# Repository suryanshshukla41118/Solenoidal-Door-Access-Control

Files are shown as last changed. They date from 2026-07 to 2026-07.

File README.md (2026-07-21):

# 🔐 Solenoid Door Access Control

An Arduino Nano–based electronic door lock system that replaces traditional mechanical keys with PIN-based authentication. Enter the correct password on a 4×4 keypad and a relay-driven solenoid lock retracts to grant access — wrong entries are rejected, logged, and locked out after repeated failures.

Designed end-to-end: schematic → PCB layout → fabrication-ready Gerbers → firmware.

---

## ✨ Features

- 🔢 **4×4 keypad PIN entry** with masked input on a 16×2 LCD
- 🔒 **Fail-safe default-locked state** — solenoid stays locked unless explicitly triggered
- ⏱️ **Auto re-lock** after a configurable unlock window
- 🚫 **Brute-force protection** — lockout timer after repeated failed attempts
- 🔁 **In-field password change** (old PIN → new PIN) with **EEPROM storage** so it survives power loss
- 🔊 **Audible + visual feedback** via buzzer and green/red status LEDs
- 🖥️ Custom two-layer **PCB** designed and routed from scratch (Gerbers + drill files included)

---

## ⚙️ How It Works

1. On power-up, the Arduino initializes all peripherals and keeps the solenoid **locked** by default.
2. The user enters a 4-digit PIN on the keypad; each digit is masked on the LCD.
3. Pressing `#` submits the PIN for verification against the stored value.
4. **Correct PIN** → relay energizes the solenoid, door unlocks, green LED + short beep, auto re-locks after a timeout.
5. **Incorrect PIN** → red LED + buzzer alert, door stays locked; after 3 failed attempts the system enters a 15-second lockout.
6. Pressing `A` at any time opens a guided password-change flow, storing the new PIN in EEPROM.

**Governing physics** (solenoid actuation):

```
F ∝ N · I          (Force generated by current through coil)
B = μNI / L         (Magnetic field in the coil)
V = IR              (Ohm's Law — current through solenoid)
P = V · I           (Power consumption, for supply/relay sizing)
```

---

## 🧰 Hardware

| Component | Details |
|---|---|
| **Microcontroller** | Arduino Nano (ATmega328P) |
| **Input** | 4×4 matrix keypad (PIN entry) |
| **Display** | 16×2 LCD (parallel interface) |
| **Actuator** | 12V DC solenoid door lock |
| **Driver** | Relay module (+ flyback diode for back-EMF protection) |
| **Feedback** | Buzzer, green LED (access granted), red LED (access denied) |
| **Power** | 5V for logic, 9–12V external supply for the solenoid |

### Pin Map (Arduino Nano)

| Function | Pin(s) |
|---|---|
| LCD (RS, E, D4–D7) | 12, 11, 5, 4, 3, 2 |
| Keypad Rows | A0, A1, A2, A3 |
| Keypad Columns | 6, 7, 8, 9 |
| Relay (solenoid driver) | 10 |
| Buzzer | A4 |
| Green LED | A5 |
| Red LED | 13 |

> Adjust pin assignments in the firmware if your wiring/PCB differs.

---

## 🖥️ Software

- **Firmware**: Arduino IDE (C/C++), using `Keypad.h`, `LiquidCrystal.h`, and `EEPROM.h`
- **Schematic capture & PCB layout**: Altium Designer
- **Circuit simulation**: Proteus VSM
- **Fabrication outputs**: Gerber (RS-274X) + Excellon drill files

---

## 🔩 PCB Design

A custom two-layer PCB was designed to host the Nano, relay, buzzer, OLED, keypad header, and power input — laid out and routed manually in Altium Designer, then exported to industry-standard Gerber/drill files for fabrication.

**Component placement (silkscreen legend):**

Keypad header, Buzzer, Relay, Nano footprint, OLED display, and 9–12V power input footprint, arranged for clean routing and minimal trace crossover.

**Signal routing (top + bottom copper):**

Signal traces connect the keypad rows/columns, relay control line, OLED I²C/SPI lines, and power rails between the Nano and peripheral footprints, with dedicated power pours for the 9–12V solenoid supply.

**Drill report summary:**

| Tool | Hole Size | Count | Type |
|---|---|---|---|
| T1 | 0.8 mm | 2 | PTH |
| T2 | 0.9 mm | 41 | PTH |
| T3 | 1.0 mm | 4 | PTH |
| T4 | 2.0 mm | 4 | PTH |
| T5 | 3.35 mm | 2 | PTH |
| T6 | 3.74 mm | 1 | PTH |

**54 total plated through-holes**, all routed with a top-to-bottom layer pair.

> Gerber files (`PCB1_Profile`, `PCB1_Legend_Top`, `PCB1_Copper_Signal_Top/Bot`) and the drill report (`PCB1.DRR`) are included in [`/hardware`](./hardware) for anyone who wants to fabricate the board.

---

## 📁 Repository Structure

```
├── firmware/
│   └── Solenoid_Door_Access_Control.ino   # Main Arduino sketch
├── hardware/
│   ├── PCB1_Profile.gbr
│   ├── PCB1_Legend_Top.gbr
│   ├── PCB1_Copper_Signal_Top.gbr
│   ├── PCB1_Copper_Signal_Bot.gbr
│   ├── PCB1.apr
│   └── PCB1.DRR
└── README.md
```

---

## 🚀 Getting Started

### 1. Hardware Assembly
Wire the components per the [pin map](#pin-map-arduino-nano) above, or fabricate the included PCB and populate it with the listed components.

### 2. Flash the Firmware
1. Open `firmware/Solenoid_Door_Access_Control.ino` in the Arduino IDE.
2. Install the required libraries via Library Manager: `Keypad`, `LiquidCrystal` (built-in), `EEPROM` (built-in).
3. Select **Board: Arduino Nano** and the correct COM port.
4. Upload.

### 3. Default Credentials
- Default PIN: `1234`
- Change it any time by pressing `A` on the keypad and following the on-screen prompts.

---

## 🛡️ Design Considerations

- **Fail-safe locking**: the solenoid defaults to locked on boot and on power loss — the door never fails open.
- **Back-EMF protection**: a flyback diode across the relay coil protects the driver transistor when the solenoid de-energizes.
- **Brute-force resistance**: a 3-strike lockout with a cooldown period discourages rapid PIN guessing.

## 🔮 Future Improvements

- RFID / NFC card authentication as a secondary input method
- Wi-Fi/Bluetooth module for remote unlock and access logging
- OTP-based one-time access codes
- Real-time access logging to an SD card or cloud endpoint

---

## 📜 License

This project is open-source — feel free to use, modify, and build on it. Consider adding a license file (e.g., MIT) if you plan to share it publicly.

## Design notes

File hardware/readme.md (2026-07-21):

# 🔐 Solenoid Door Access Control

An Arduino Nano–based PIN authentication door lock. Enter your PIN on a 4×4 keypad — correct entries release a relay-driven solenoid, wrong entries get rejected and locked out after repeated tries.

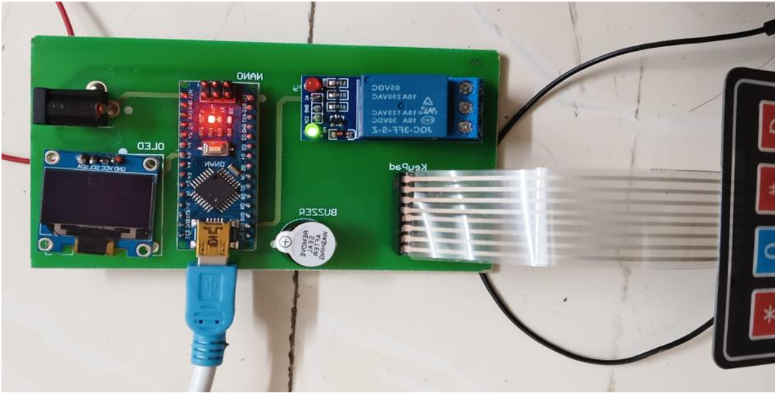
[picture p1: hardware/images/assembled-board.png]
Assembled Board


## Quick Overview
- 4×4 keypad PIN entry with LCD feedback
- Fail-safe: stays locked by default
- Auto re-lock + brute-force lockout after failed attempts
- In-field PIN change, saved to EEPROM
- Custom 2-layer PCB (Gerbers included)

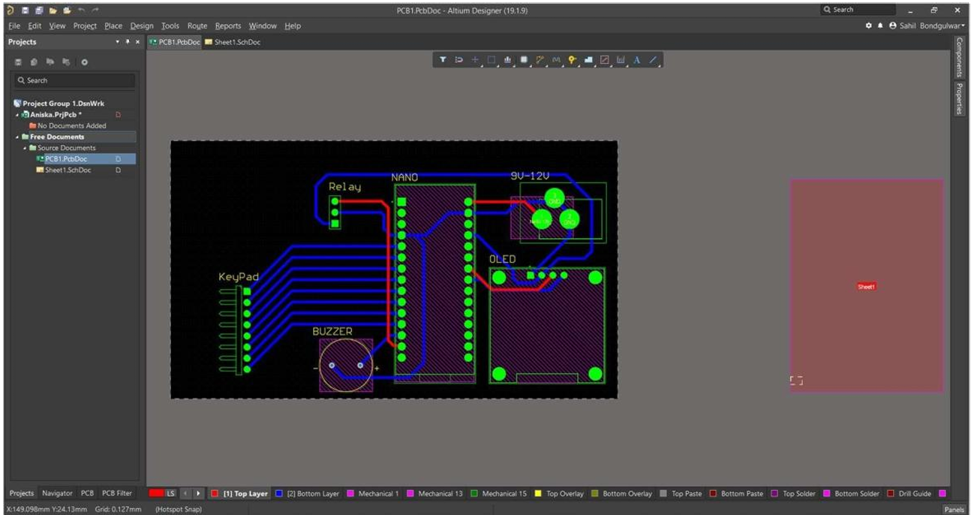
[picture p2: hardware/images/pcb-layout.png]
PCB Layout


## Hardware
Arduino Nano · 4×4 keypad · 16×2 LCD · 12V solenoid · relay module · buzzer + LEDs

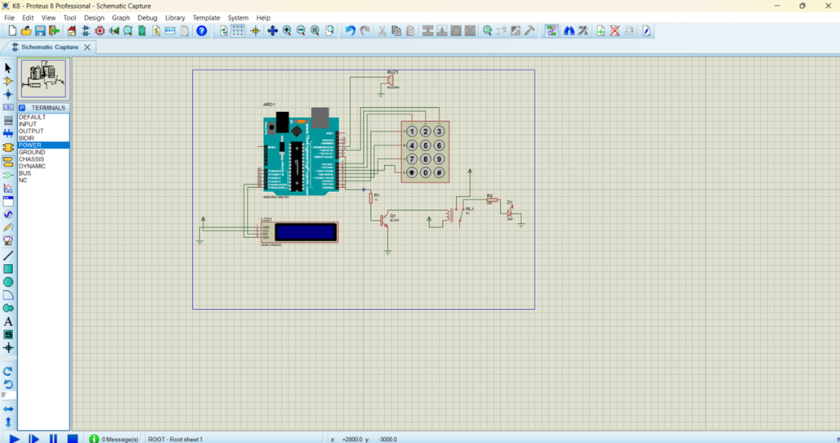
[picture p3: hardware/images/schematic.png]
Schematic


## Getting Started
1. Wire per the pin map (see full README) or use the included PCB
2. Flash `firmware/Solenoid_Door_Access_Control.ino` via Arduino IDE
3. Install libraries: `Keypad`, `LiquidCrystal`, `EEPROM`
4. Default PIN is `1234` — change it anytime with the `A` key

## Full Details
See the main [README](./README.md) for pin mapping, PCB drill report, repo structure, and design notes.

## License
Open-source — feel free to use, modify, and build on it.

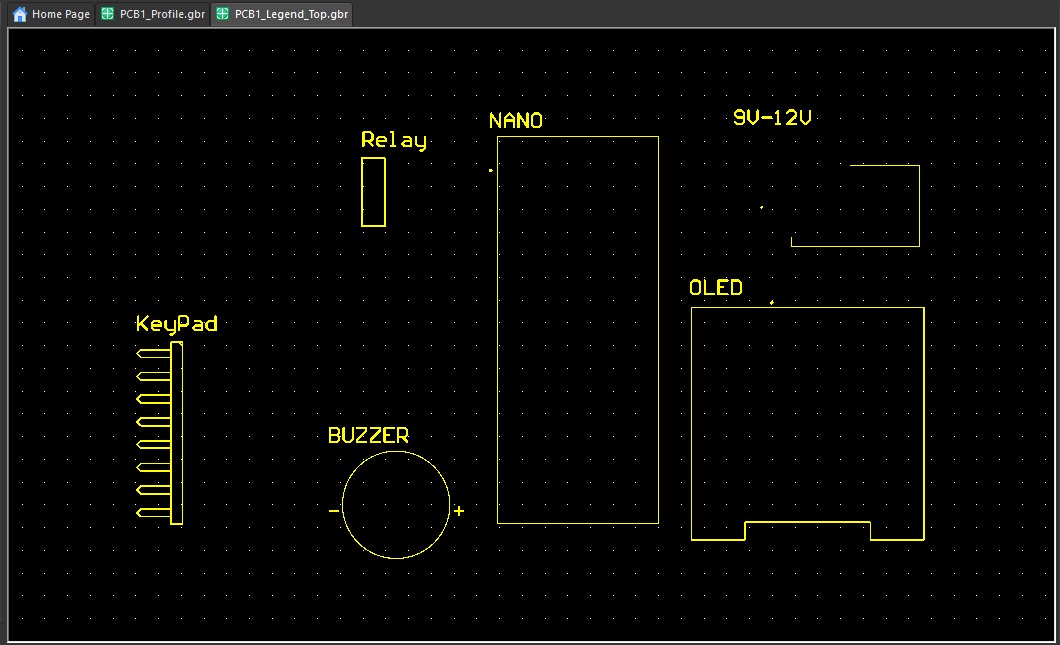
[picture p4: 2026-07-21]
hardware/images/PCB1_Legend_TOP_gbr.jpeg

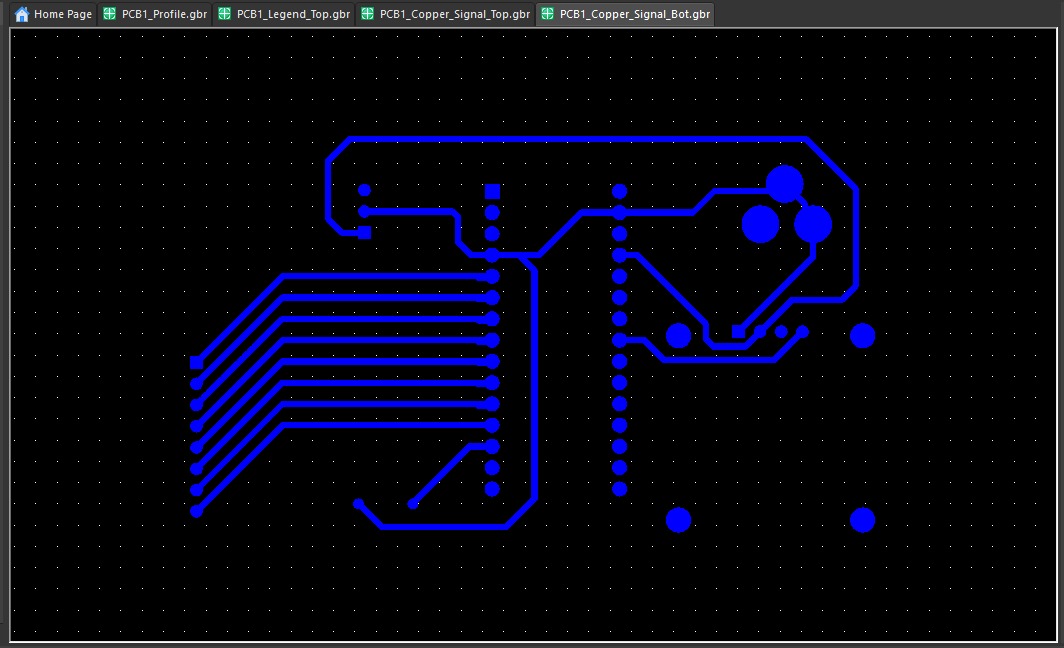
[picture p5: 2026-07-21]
hardware/images/PCB1_copper_signal_BOTTOM_gbr.jpeg

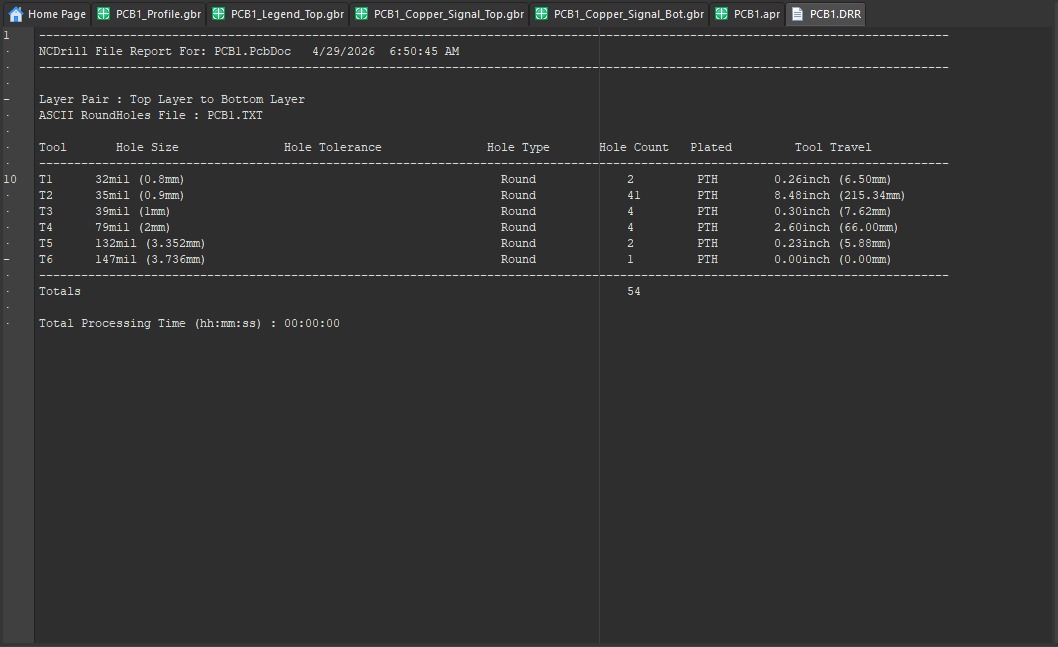
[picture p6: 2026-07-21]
hardware/images/PCB1_DBR.jpeg

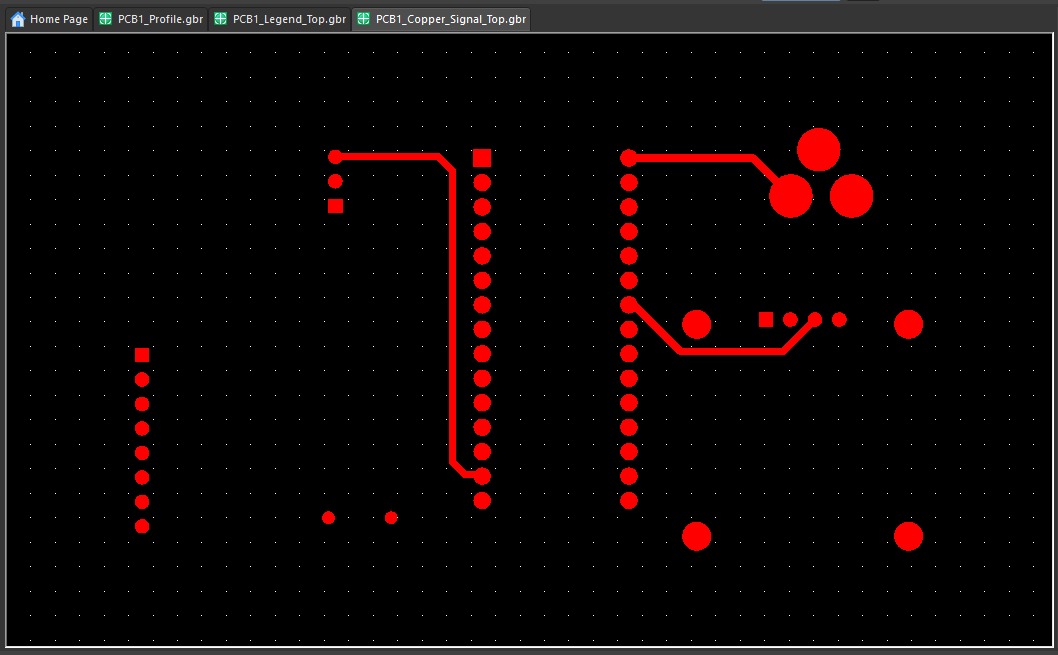
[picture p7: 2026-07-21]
hardware/images/PCB1_copper_Signal_TOP.jpeg

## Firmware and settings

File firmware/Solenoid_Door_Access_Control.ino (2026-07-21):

#include <Keypad.h>
#include <LiquidCrystal.h>
#include <EEPROM.h>

// ---------------- LCD Setup (16x2, parallel) ----------------
// Wiring: RS, E, D4, D5, D6, D7
LiquidCrystal lcd(12, 11, 5, 4, 3, 2);

// ---------------- Keypad Setup (4x4) ----------------
const byte ROWS = 4;
const byte COLS = 4;

char keys[ROWS][COLS] = {
  {'1','2','3','A'},
  {'4','5','6','B'},
  {'7','8','9','C'},
  {'*','0','#','D'}
};

// NOTE: Adjust these pins to match your wiring / free pins on the Nano.
// Avoid pins already used by the LCD above (2,3,4,5,11,12).
byte rowPins[ROWS] = {A0, A1, A2, A3};   // R1, R2, R3, R4
byte colPins[COLS] = {6, 7, 8, 9};       // C1, C2, C3, C4

Keypad keypad = Keypad(makeKeymap(keys), rowPins, colPins, ROWS, COLS);

// ---------------- Output Pins ----------------
const int RELAY_PIN   = 10;   // Drives relay -> solenoid lock (Active LOW relay module typical)
const int BUZZER_PIN  = A4;
const int GREEN_LED   = A5;
const int RED_LED     = 13;

// ---------------- Password / Security Settings ----------------
const byte PASSWORD_LENGTH = 4;      // 4-digit PIN
char storedPassword[PASSWORD_LENGTH + 1] = "1234"; // default PIN
char inputPassword[PASSWORD_LENGTH + 1];
byte inputIndex = 0;

const unsigned long UNLOCK_DURATION = 4000;   // ms solenoid stays unlocked
const byte MAX_ATTEMPTS = 3;
byte failedAttempts = 0;
const unsigned long LOCKOUT_DURATION = 15000; // ms lockout after max failed attempts

const int EEPROM_ADDR = 0; // where password is stored in EEPROM

// ---------------- Setup ----------------
void setup() {
  pinMode(RELAY_PIN, OUTPUT);
  pinMode(BUZZER_PIN, OUTPUT);
  pinMode(GREEN_LED, OUTPUT);
  pinMode(RED_LED, OUTPUT);

  lockDoor(); // ensure locked state at startup (safety default)

  lcd.begin(16, 2);
  loadPasswordFromEEPROM();

  showIdleScreen();
}

// ---------------- Main Loop ----------------
void loop() {
  char key = keypad.getKey();

  if (key) {
    tone(BUZZER_PIN, 1000, 50); // short beep on keypress

    if (key == '#') {
      // '#' = submit / check password
      checkPassword();
    }
    else if (key == '*') {
      // '*' = clear current entry
      resetInput();
      showIdleScreen();
    }
    else if (key == 'A') {
      // 'A' = enter password-change mode
      changePasswordFlow();
    }
    else {
      // Regular digit entry
      if (inputIndex < PASSWORD_LENGTH) {
        inputPassword[inputIndex] = key;
        inputIndex++;
        inputPassword[inputIndex] = '\0';
        updatePasswordDisplay();
      }
    }
  }
}

// ---------------- Core Functions ----------------

void checkPassword() {
  inputPassword[inputIndex] = '\0';

  if (strcmp(inputPassword, storedPassword) == 0) {
    accessGranted();
  } else {
    accessDenied();
  }
  resetInput();
}

void accessGranted() {
  failedAttempts = 0;

  lcd.clear();
  lcd.setCursor(0, 0);
  lcd.print("Access Granted");
  digitalWrite(GREEN_LED, HIGH);
  digitalWrite(RED_LED, LOW);
  tone(BUZZER_PIN, 1500, 200);

  unlockDoor();
  delay(UNLOCK_DURATION);
  lockDoor();

  digitalWrite(GREEN_LED, LOW);
  showIdleScreen();
}

void accessDenied() {
  failedAttempts++;

  lcd.clear();
  lcd.setCursor(0, 0);
  lcd.print("Access Denied");
  digitalWrite(RED_LED, HIGH);
  tone(BUZZER_PIN, 400, 400);
  delay(1000);
  digitalWrite(RED_LED, LOW);

  if (failedAttempts >= MAX_ATTEMPTS) {
    lockoutSequence();
  } else {
    showIdleScreen();
  }
}

void lockoutSequence() {
  lcd.clear();
  lcd.setCursor(0, 0);
  lcd.print("Too many tries");
  lcd.setCursor(0, 1);
  lcd.print("Wait 15s...");

  for (int i = 0; i < 5; i++) {
    digitalWrite(RED_LED, HIGH);
    tone(BUZZER_PIN, 300, 150);
    delay(150);
    digitalWrite(RED_LED, LOW);
    delay(150);
  }

  delay(LOCKOUT_DURATION - 1500 > 0 ? LOCKOUT_DURATION - 1500 : 0);
  failedAttempts = 0;
  showIdleScreen();
}

void unlockDoor() {
  digitalWrite(RELAY_PIN, HIGH); // Active-HIGH trigger; invert to LOW if using active-LOW relay module
}

void lockDoor() {
  digitalWrite(RELAY_PIN, LOW);  // default locked state
}

void resetInput() {
  inputIndex = 0;
  inputPassword[0] = '\0';
}

void showIdleScreen() {
  lcd.clear();
  lcd.setCursor(0, 0);
  lcd.print("Enter Password:");
  lcd.setCursor(0, 1);
}

void updatePasswordDisplay() {
  lcd.setCursor(0, 1);
  for (byte i = 0; i < inputIndex; i++) {
    lcd.print('*'); // mask entered digits
  }
  lcd.print("    "); // clear trailing chars
}

// ---------------- Password Change Flow ----------------
void changePasswordFlow() {
  resetInput();
  lcd.clear();
  lcd.setCursor(0, 0);
  lcd.print("Old Password:");
  lcd.setCursor(0, 1);

  char oldPass[PASSWORD_LENGTH + 1];
  byte idx = 0;

  while (idx < PASSWORD_LENGTH) {
    char k = keypad.getKey();
    if (k && k >= '0' && k <= '9') {
      oldPass[idx++] = k;
      lcd.print('*');
      tone(BUZZER_PIN, 1000, 50);
    }
  }
  oldPass[idx] = '\0';

  if (strcmp(oldPass, storedPassword) != 0) {
    lcd.clear();
    lcd.print("Wrong Password");
    tone(BUZZER_PIN, 400, 400);
    delay(1500);
    showIdleScreen();
    return;
  }

  lcd.clear();
  lcd.setCursor(0, 0);
  lcd.print("New Password:");
  lcd.setCursor(0, 1);

  char newPass[PASSWORD_LENGTH + 1];
  idx = 0;
  while (idx < PASSWORD_LENGTH) {
    char k = keypad.getKey();
    if (k && k >= '0' && k <= '9') {
      newPass[idx++] = k;
      lcd.print('*');
      tone(BUZZER_PIN, 1000, 50);
    }
  }
  newPass[idx] = '\0';

  strcpy(storedPassword, newPass);
  savePasswordToEEPROM();

  lcd.clear();
  lcd.print("Password Set!");
  tone(BUZZER_PIN, 1500, 200);
  delay(1500);
  showIdleScreen();
}

// ---------------- EEPROM Helpers ----------------
void savePasswordToEEPROM() {
  for (byte i = 0; i < PASSWORD_LENGTH; i++) {
    EEPROM.update(EEPROM_ADDR + i, storedPassword[i]);
  }
}

void loadPasswordFromEEPROM() {
  bool valid = true;
  char temp[PASSWORD_LENGTH + 1];

  for (byte i = 0; i < PASSWORD_LENGTH; i++) {
    char c = EEPROM.read(EEPROM_ADDR + i);
    if (c < '0' || c > '9') {
      valid = false;
      break;
    }
    temp[i] = c;
  }
  temp[PASSWORD_LENGTH] = '\0';

  if (valid) {
    strcpy(storedPassword, temp);
  } else {
    // First run: store the default password
    savePasswordToEEPROM();
  }
}

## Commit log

2026-07-21 Rename WhatsApp Image 2026-07-21 at 10.14.10 PM.jpeg to PCB1_Legend_TOP_gbr.jpeg
2026-07-21 Rename WhatsApp Image 2026-07-21 at 10.14.11 PM (1).jpeg to PCB1_copper_signal_BOTTOM_gbr.jpeg
2026-07-21 Rename WhatsApp Image 2026-07-21 at 10.14.11 PM (2).jpeg to PCB1_DBR.jpeg
2026-07-21 Rename WhatsApp Image 2026-07-21 at 10.14.11 PM.jpeg to PCB1_copper_Signal_TOP.jpeg
